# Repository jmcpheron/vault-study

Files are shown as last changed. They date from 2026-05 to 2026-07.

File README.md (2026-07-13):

# Vault Study

We're recreating **Adam Savage's miniature (1/12-scale) bank-vault
door** — the one he machines on his
[Tested YouTube series](https://www.tested.com/) — as a public
**Onshape** model anyone can open and play with. Second act: the
same mechanism converted into a parametric design an FDM printer
can build.

## The model — try it

The faithful variant is a CAD reinterpretation of Adam's machined
design: module-0.5 gears, a 120-tooth ring + 12 × 24-tooth spurs,
12 rack-driven locking pins, a combination lock as gatekeeper.

- **[Open it in Onshape ↗](https://cad.onshape.com/documents/eaf3e87c1faae12ad867b335/w/83a96bb8921d1af3abd7aecd/e/9db299b535aaeded5de5120c)**
  — the live document. Drag the mechanism; with a free Onshape
  account you can copy the workspace and take it apart.
- **[Download the STEP](step-source/)** — the committed export, for
  any other CAD package.
- **[Interactive demo](https://jmcpheron.github.io/vault-study/interactive/)**
  — no CAD required; a slider drives all twelve pins in the browser.

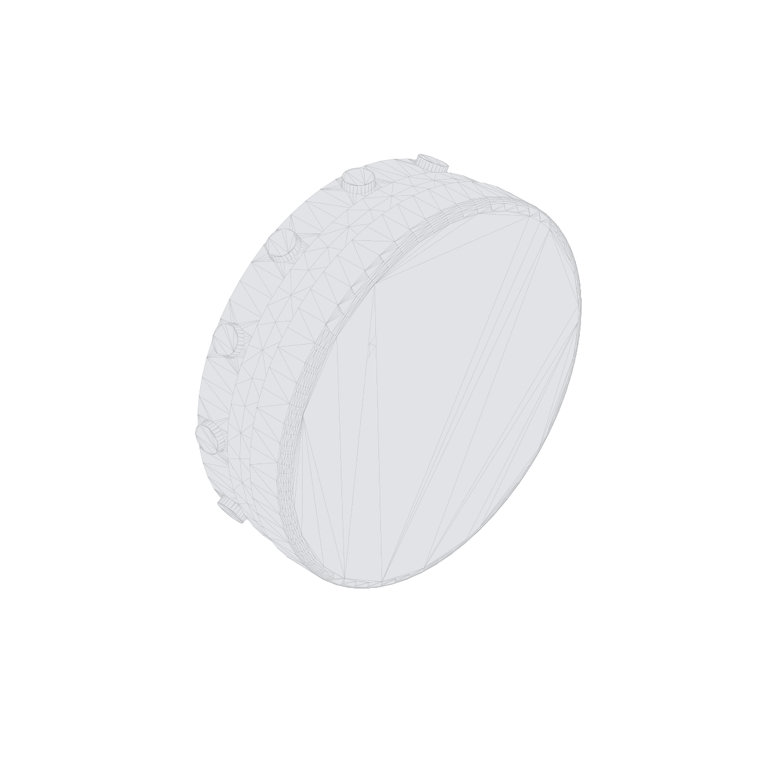
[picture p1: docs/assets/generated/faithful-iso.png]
Faithful variant, isometric render


Both documents are still being built — expect half-finished
geometry, and check the [build blog](https://jmcpheron.github.io/vault-study/)
for where things stand.

## The FDM conversion

The second act redesigns the same mechanism for desktop 3D
printers: cylinders become hex stock (anti-rotation without
keyways), tolerances loosen, parts orient to avoid supports. Aims
to be printable on a stock Bambu A1 / Prusa Mini class machine in
one evening's worth of jobs.

- **[Open the FDM variant in Onshape ↗](https://cad.onshape.com/documents/017898deda56c430272a5497/w/5d7667d0936a708006b152fa/e/8e68069be3521bc23b864206)**
- [`cad/fdm/deviations.md`](cad/fdm/deviations.md) — the home for
  every "why is the FDM one different?" answer.
- End state: a 3MF bundle on **MakerWorld** and **Printables** that
  anyone can print at home without reading any of this. _(Soon.)_

## The blog

**[jmcpheron.github.io/vault-study ↗](https://jmcpheron.github.io/vault-study/)**
— a visual development blog: exploded views, the gear math, pin
tolerance stack-ups, and the design decisions as they happen. The
evergreen reference pages (mechanics, gearing math, faithful-vs-FDM)
live there too.

## What's where

| Path | What it is |
| --- | --- |
| [`specs.md`](specs.md) | Canonical dimensions, source-tagged to the video they came from. The keystone. |
| [`cad/faithful/`](cad/faithful/) | Faithful-variant docs: Onshape doc link, modeling notes, FeatureScript settings. |
| [`cad/fdm/`](cad/fdm/) | FDM-variant docs + [`deviations.md`](cad/fdm/deviations.md). |
| [`step-source/`](step-source/) | Raw STEP exports from Onshape. The inbox; the tooling reads from here. |
| [`docs/`](docs/) | GitHub Pages site: the development blog + reference pages (Jekyll). |
| [`src/vaultkit/`](src/vaultkit/) | Python kernel — gear + tolerance math, and the render pipeline behind the blog's visuals. |
| [`log.md`](log.md) | Terse workshop journal. The blog is its illustrated public face. |

## Status (live links)

| Variant | Onshape | MakerWorld | Printables |
| --- | --- | --- | --- |
| Faithful | [open in Onshape ↗](https://cad.onshape.com/documents/eaf3e87c1faae12ad867b335/w/83a96bb8921d1af3abd7aecd/e/9db299b535aaeded5de5120c) | n/a (CAD study) | n/a (CAD study) |
| FDM | [open in Onshape ↗](https://cad.onshape.com/documents/017898deda56c430272a5497/w/5d7667d0936a708006b152fa/e/8e68069be3521bc23b864206) | _(soon)_ | _(soon)_ |

## How the visuals get made

Every diagram, table, and animation on the blog is *derived* — from
the Onshape STEP exports plus one canonical parameter file — by the
`vaultkit` Python kernel:

```
   Onshape docs ──STEP──▶ step-source/ ──vaultkit──▶ docs/ (blog + SVG/GIF/PNG)
                                             │
                                             └──▶ MakerWorld + Printables (3MF)
```

```bash
# Light install — gear + tolerance math, SVG diagrams, tests
pip install -e ".[dev]"

vaultkit gears info   # the gear-math summary derived from specs.md
vaultkit play         # the pin-play tolerance stack-up, faithful vs FDM

pytest                # includes the specs.md ↔ params.py drift test
ruff check src tests
```

The heavy CAD libraries (cadquery-ocp, trimesh, etc.) power the
STEP inspection and 3D renders and live behind
`pip install -e ".[heavy]"`, so contributors who only want to edit
prose aren't forced into a 180 MB OpenCascade wheel.

The repo follows the **Shareable CAD** pattern (Onshape → GitHub →
MakerWorld/Printables); the pattern doc is
[`SHAREABLE-CAD.md`](SHAREABLE-CAD.md).

## Attribution

Mechanism design, proportions, and gear math are Adam Savage's,
shown on the Tested YouTube series. This repo is an independent
educational CAD reinterpretation. Full attribution and source
links in [`ACKNOWLEDGMENTS.md`](ACKNOWLEDGMENTS.md).

## Licenses

- **Code** (`vaultkit`, tests, configs): MIT — see [`LICENSE`](LICENSE).
- **3D geometry** (STEP files, derived STL/3MF/renders): CC BY-SA 4.0
  — see [`LICENSE-3D-FILES`](LICENSE-3D-FILES).

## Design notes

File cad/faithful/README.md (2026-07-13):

# Faithful variant

A CAD reinterpretation of Adam Savage's machined 1/12-scale vault door
as built on the Tested YouTube series. The geometry follows Adam's
dimensions exactly — same materials called out in [`../../specs.md`](../../specs.md),
same gear math, same combination-lock-as-gatekeeper.

## Onshape document

**Public, view-only:**
[cad.onshape.com/documents/eaf3e87c…](https://cad.onshape.com/documents/eaf3e87c1faae12ad867b335/w/83a96bb8921d1af3abd7aecd/e/9db299b535aaeded5de5120c)

The canonical IDs (document / workspace / element) and the pinned
Onshape **Version** for the current STEP live in
[`../../src/vaultkit/params.py`](../../src/vaultkit/params.py) under
`ONSHAPE["faithful"]` — the one place the tooling reads. Current STEP:
**live workspace export** (no named Version pinned yet).

The Onshape document is the **source of truth** for geometry. The
STEP export sits at [`../../step-source/faithful-vault.step`](../../step-source/faithful-vault.step).
When the Onshape document updates, re-export STEP
and replace that file — see [`../../SHAREABLE-CAD.md`](../../SHAREABLE-CAD.md)
for the cut-a-Version → export → commit loop.

## Modeling conventions

See [`onshape.md`](onshape.md) for FeatureScript settings and the
Assembly-tab mate strategy that turns one modelled spur into the
timed 12-pin mechanism.

## Bill of materials

_(Will be auto-generated by `vaultkit bom` once the heavy pipeline
lands. For now, see [`../../specs.md`](../../specs.md) — every part
and dimension is enumerated there.)_

## Differences from Adam's build (acknowledged, not "fixes")

- We aren't actually building a physical one in cast iron and brass.
  CAD takes the geometry; the materials are FYI.
- The lapping-plate flatness work, the hand-threading concentricity
  fights, the dividing-plate fixturing — all the rich physical-shop
  knowledge from the videos — exists in the docs as commentary
  ([`docs/build-log.md`](../../docs/build-log.md),
  [`docs/sources.md`](../../docs/sources.md)) but doesn't change the
  CAD.

## Related

- [`../fdm/`](../fdm/) — the printable-at-home variant. Same
  mechanism, redesigned for FDM.
- [`../../docs/mechanics.md`](../../docs/mechanics.md) — how the
  whole thing works as a single system.

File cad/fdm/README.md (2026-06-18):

# FDM variant

The same vault mechanism, redesigned for desktop FDM 3D printers.
Aims to print on a stock Bambu A1 / Prusa Mini class machine in one
evening's worth of jobs, no supports required, no post-machining,
no specialty filaments.

Design philosophy: **preserve the mechanism, swap the manufacturing
language.** Cylinders become hex stock so anti-rotation comes from
geometry instead of keyways. Tolerances loosen from "0.020 in
clearance everywhere" to FDM-realistic numbers. Layer orientation
is chosen per-part. See [`deviations.md`](deviations.md) for the
running list of "why is the FDM one different here?" answers.

## Onshape document

**Public, view-only:**
[cad.onshape.com/documents/017898de…](https://cad.onshape.com/documents/017898deda56c430272a5497/w/5d7667d0936a708006b152fa/e/8e68069be3521bc23b864206)

Canonical IDs + the pinned Onshape **Version** for the current STEP
live in [`../../src/vaultkit/params.py`](../../src/vaultkit/params.py)
under `ONSHAPE["fdm"]`. Current STEP: **live workspace export** (no
named Version pinned yet — see
[`../../SHAREABLE-CAD.md`](../../SHAREABLE-CAD.md) for the export loop).

Early STEP export already in
[`../../step-source/fdm-vault.step`](../../step-source/fdm-vault.step).

## Modeling conventions

See [`onshape.md`](onshape.md) for FDM-specific FeatureScript settings
and Assembly notes. Inherits from
[`../faithful/onshape.md`](../faithful/onshape.md); only differences
are recorded.

## Print profile

_(Will live alongside the 3MF bundle once that ships. Aim: 0.2 mm
layer height, 4-wall perimeter on the geared parts, PETG for the
mechanism, PLA for the cosmetic puck.)_

## MakerWorld + Printables

| Site | Status |
| --- | --- |
| MakerWorld | _(not yet listed)_ |
| Printables | _(not yet listed)_ |

When the first listing goes live, paste the URL here, and link back
from the listing description to this repo + the Onshape doc.

## Related

- [`../faithful/`](../faithful/) — the machined-replica variant.
- [`deviations.md`](deviations.md) — the canonical log of FDM
  design choices.
- [`../../docs/fdm-variant.md`](../../docs/fdm-variant.md) — the
  human-facing explainer page about *why* these choices were made.

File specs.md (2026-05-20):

# Vault — specifications

Single source of truth for every dimension, count, and material call-out in
the Adam-Savage-faithful design. Every row is tagged with the source video
it came from (`[part-N]`), so when Adam revises a number in a later video
the trail stays clear.

Numbers here are the **canonical** values for the faithful variant. They
are mirrored into [`src/vaultkit/params.py`](src/vaultkit/params.py) by
hand; the drift test in [`tests/test_no_drift.py`](tests/test_no_drift.py)
fails if the two get out of sync. The FDM variant inherits these defaults
and deviates where noted in [`cad/fdm/deviations.md`](cad/fdm/deviations.md).

When a value is superseded, the old row is kept (struck through, marked
`superseded in [part-N]`) and the new row sits below it (marked `live`).
The history is the lesson — parametric design exists *because* numbers
move. The drift test only checks `live` rows.

Sources legend:

- `[part-1]` — Ring gear machining
  (https://www.youtube.com/watch?v=SiL8IzJSnyU)
- `[part-2]` — Locking pins, racks, main door body
- `[part-3]` — Vault door (heavy puck), frame, hinge
- `[part-4]` — Concentricity, rack refinement, pin-diameter revision
- `[part-5]` — Combination lock

---

## Global gear math

| Parameter | Value | Source |
| --- | --- | --- |
| Gear module | 0.5 mm | [part-1] |
| Scale (relative to a real vault door) | 1/12 | [part-1] |

The module is the parameter that must match across every gear that meshes,
so it is the single most important number in the file. A real vault door
uses 24 spur gears (24 teeth each) around a 288-tooth ring gear; Adam
halves the math for his 1/12-scale build.

## Ring gear

| Parameter | Value | Source |
| --- | --- | --- |
| Teeth | 120 | [part-1] |
| Outer diameter | 2.401 in (≈ 2.4 in) | [part-1] |
| Inner diameter (slip-fit on acrylic boss) | 2.003 in | [part-2] |
| Depth of gear cut (OD to root of tooth) | 0.044 in | [part-1] |
| Material (Adam's build, FYI only) | 416 stainless | [part-1] |

## Spur gears

| Parameter | Value | Source |
| --- | --- | --- |
| Count | 12 | [part-1] |
| Teeth (each) | 24 | [part-1] |
| Bolt-circle diameter (BCD) | 72 mm | [part-2] |
| Bolt-circle hole spacing | 30° (12 holes evenly around) | [part-1] |
| Axle | Shoulder bolt, 0.1 mm smaller than gear bore (slip-fit) | [part-2] |

Adam's mill dividing plate has 24 holes (15° spacing); he fills every
other one for the 12-pin door. In CAD: a 12-point circular pattern on a
72 mm BCD.

## Locking pins

| Parameter | Value | Source | Status |
| --- | --- | --- | --- |
| Count | 12 (one per spur gear) | [part-1] | live |
| Diameter | ~~12 mm~~ | [part-1], [part-2] | superseded in [part-4] |
| Diameter | **10 mm** | [part-4] | live |
| Length | 30 mm | [part-2] | live |
| Base thread | M6 (rack screws into pin base) | [part-2] | live |

The 12 mm → 10 mm revision is the textbook reason this repo is
parametric: change `PIN_DIAMETER_MM` in `params.py` and the radial
bores in the acrylic hub, the cast-iron puck, and the FDM-variant
hex stock all follow.

## Racks (drive the pins)

| Parameter | Value | Source |
| --- | --- | --- |
| Stock | 8 mm × 8 mm square | [part-2] |
| Module (matches ring + spur) | 0.5 mm | [part-2] |
| Threaded end | Turned down to 6 mm shaft, M6 thread | [part-2] |
| Clearance cut | Curved relief on back face (clears ring gear) | [part-2], [part-4] |
| Quantity machined | 14 (need 12; "always make more than you need") | [part-4] |

The threaded stud must be concentric to the 8 × 8 stock to within
~0.0125" or the pins bind on the door bores. Adam fixes this with an
8 mm square 5C collet + spindle lock + tailstock die — see [part-4].

## Main door body (acrylic hub)

The clear-acrylic puck that houses the mechanism and lets the gears
be visible.

| Parameter | Value | Source |
| --- | --- | --- |
| Outer diameter | 6 in | [part-2] |
| Thickness (stock) | 1.25 in | [part-2] |
| Material | Cast acrylic (not extruded — extruded melts on the lathe) | [part-2] |
| Ring-gear slip-fit boss diameter | 2.003 in | [part-2] |
| Radial pin bores | 12 × 12 mm dia | [part-2] |

Note: the radial pin bores were sized to the original 12 mm pins; on
a follow-on revision they need to drop to 10 mm to match the
[locking-pin revision in part-4](#locking-pins). Track that change
here when it lands.

## Heavy door puck (cast iron outer)

| Parameter | Value | Source | Status |
| --- | --- | --- | --- |
| Material | ~~Steel~~ | [part-3] | superseded mid-[part-3] |
| Material | **Cast iron** | [part-3] | live |
| Target weight (real-life) | 15–20 lb | [part-3] | live |
| Outer diameter (fits frame hole) | 6 in | [part-3] | live |
| Front-face thickness (solid) | 0.5 in | [part-3] | live |
| Edge taper (nominal) | ~10° (built as three stepped angles) | [part-3] | live |
| Closure depth into frame | 0.75 in (limited by hinge clearance) | [part-3] | live |

The tapered edge is what makes a vault door "thunk" home into the
frame. Adam estimates ~10° but breaks it into three slightly
different stepped angles — exact values TBD.

## Door frame

| Parameter | Value | Source |
| --- | --- | --- |
| Material | 1/2 in 6061 aluminum plate | [part-3] |
| Overall size | 10–12 in square | [part-3] |
| Door opening (centered) | 6 in dia | [part-3] |
| Door-to-frame clearance | 0.020 in (20 thou) | [part-3] |

## Hinge

| Parameter | Value | Source |
| --- | --- | --- |
| Thrust-bearing OD | 3/8 in | [part-3] |
| Center pin | 1/8 in | [part-3] |
| Fasteners | 28 × M2 screws | [part-3] |
| Hinge-hole inner column (X from door center) | 0.245 in | [part-3] |
| Hinge-hole column spacing | 0.508 in | [part-3] |
| Hinge-hole outer column (X = inner + spacing) | 0.753 in | [part-3] |
| Hinge-hole Y span (± from center) | 0.9125 in | [part-3] |

Adam's Plan B if the M2s fail under load: M6. CAD stays with M2.

## Combination lock

| Parameter | Value | Source |
| --- | --- | --- |
| Cage envelope | 0.75 in × 0.5 in | [part-5] |
| Cage material | 0.025 in (25 thou) brass sheet (~0.5 mm) | [part-5] |
| Combination wheels | 3 | [part-5] |
| Wheel diameter | 0.450 in | [part-5] |
| Wheel features (each) | Spindle hole + drive tab + locking slot | [part-5] |
| Front-dial spindle | 1/8 in brass rod | [part-5] |
| Front-dial divisions | 36 (10° each) | [part-5] |
| Front-dial tick lengths | 3 (short / medium / long, every 1/5/10) | [part-5] |

Bell-crank linkage couples the drop-arm to the ring gear: when the
three wheels' locking slots align, the arm drops, the bell crank
unlocks the ring gear, the user throws the lever, all 12 pins extend.

## Derived values

These fall out of the canonical numbers above. The kernel computes
them in [`gears.py`](src/vaultkit/gears.py) so prose can read them
without hard-coding.

| Parameter | Value | Derivation |
| --- | --- | --- |
| Drive ratio (ring : spur) | 5 : 1 | 120 / 24 |
| Teeth between adjacent spur-gear axes | 10 | 120 / 12 (timing math, [part-2]) |
| Ring-gear pitch diameter | 60 mm | module × teeth = 0.5 × 120 |
| Spur-gear pitch diameter | 12 mm | module × teeth = 0.5 × 24 |
| Spur-gear axis radius (from door center) | 36 mm | (ring PD + spur PD) / 2 |

The 36 mm spur-axis radius derived from gear math should match the
72 mm BCD measured by Adam (= 2 × 36). It does — and that
agreement is one of the things the [drift test](tests/test_no_drift.py)
silently confirms.

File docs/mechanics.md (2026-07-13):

---
title: Mechanics overview
---

# Mechanics overview

<p style="text-align:center; margin: 1em 0;">
  <picture>
    <source srcset="{{ '/assets/generated/mechanism-exploded-fdm.webp' | relative_url }}" type="image/webp">
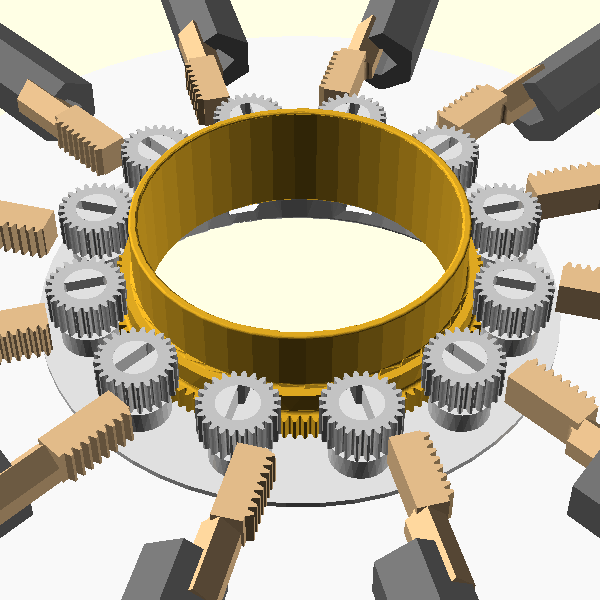
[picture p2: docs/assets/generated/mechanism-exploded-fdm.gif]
The vault mechanism in an exploded view: ring gear, twelve spur gears, twelve racks, twelve locking pins, hub plate, and base, fanning out radially from their assembled positions and returning.
    
  </picture>
</p>

The vault is a **one-knob lock**. We turn the dial, twelve pins shoot
outward into the frame in unison, and that's the whole thing. Under
the hood it's a chain of three motions, each multiplying the last:

1. **Combination lock → bell crank → ring gear.** Three watchmaker-scale
   wheels in a brass cage form the lock. Dial the right combination,
   a drop arm falls through three aligned slots, a bell crank pivots,
   and the giant **120-tooth ring gear** at the centre of the door is
   released. See [the combination lock]({{ '/combination-lock/' | relative_url }}).
2. **Ring gear → twelve spur gears.** The ring's 120 internal teeth
   mesh with twelve identical **24-tooth spur gears** spaced 30°
   apart. One turn of the ring spins every spur five times. The
   tooth-count ratio is 120 : 24 = 5 : 1; the
   [gearing-math page]({{ '/gearing-math/' | relative_url }}) walks through where the 5
   comes from.
3. **Spur gears → racks → pins.** Each spur drives a square **8 mm × 8 mm
   rack** with module-0.5 teeth on one face. The rack carries a
   **10 mm locking pin** threaded onto its end. As the spur rotates,
   the rack — and the pin attached to it — translates radially
   outward, through a bore in the door body, and into a matching bore
   in the frame.

With all twelve pins extended, the door is locked: each pin couples
it to the surrounding frame. Unlock the bell crank, throw the lever
in reverse, every pin retracts at once, and the door swings open. One
input, twelve coordinated motions — the whole point of the gear
chain.

The chain is **timed**: ring teeth (120) divided by pin count (12)
is 10. There are exactly ten ring teeth between adjacent spur axes.
The arithmetic isn't optional. If 120 ÷ 12 weren't a whole number,
the spurs couldn't all sit in matching phase relative to the ring's
tooth pattern, and the racks would push their pins to subtly
different depths. Adam emphasises this in
[part-2 of the build series]({{ '/sources/' | relative_url }}); the kernel enforces it in
[`vaultkit.gears.teeth_between_satellites`](https://github.com/jmcpheron/vault-study/blob/main/src/vaultkit/gears.py).

## The 12-spur crowding question

The animated diagram above places the twelve spur centres at the
**gear-math-derived radius** of 24 mm from the door centre — the
distance at which the spurs' teeth actually mesh with the ring's. At
that radius, twelve spurs of 12 mm diameter each are nearly
touching (their centres are 12.57 mm apart on the bolt circle, against
spur diameters of 12 mm — 0.57 mm of physical clearance). Adam's
build-video measurements report a 72 mm bolt-circle (36 mm radius),
where the spurs are much further apart — but at 36 mm, the spur teeth
would never reach the ring at all.

There's a real CAD discrepancy here, called out in
[`specs.md`](https://github.com/jmcpheron/vault-study/blob/main/specs.md#derived-values).
The [interactive page]({{ '/interactive/' | relative_url }}) lets you flip between the
two layouts and see the difference.

## See also

- [Gearing math]({{ '/gearing-math/' | relative_url }}) — module, tooth counts, where 5 : 1 comes from.
- [Interactive builder]({{ '/interactive/' | relative_url }}) — drag the slider, watch the pins extend.
- [Why twelve pins?]({{ '/why-twelve-pins/' | relative_url }}) — the divisor argument and base-12 elegance.
- [The combination lock]({{ '/combination-lock/' | relative_url }}) — the gatekeeper at the start of the chain.
- [Faithful vs FDM]({{ '/faithful-vs-fdm/' | relative_url }}) — what changes when you redesign for 3D printers.

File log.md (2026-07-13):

# Build log

Reverse-chronological session notes. Newest entries on top. Format
suggestion (not enforced): a date heading, then any mix of what you
modeled, what you learned, what you had to revise, what you got stuck
on. Keep it short — this is for future-you, not for an audience. The
public, illustrated version of this journal is the
[build blog](https://jmcpheron.github.io/vault-study/); this file
stays the terse workshop record.

---

## 2026-07-13 — Refocus: the site is now a build blog

Re-weighted the repo around what it was always about: the Onshape
model first (open it, drag it), the FDM conversion second, the
tooling demoted to a supporting role. The Pages front page is now a
chronological build blog seeded with five posts — kickoff, the
pin-travel math, the 12 mm → 10 mm pin story, the exploded views,
and a new pin-play tolerance stack-up backed by `vaultkit play` and
a generated diagram. Removed the `vault-notes-from-youtube/` scratch
as promised, and fixed every inter-page link the pretty-permalink
setup had silently broken.

## 2026-05-19 — Repo bootstrap

Scaffolded the repo following the Shareable CAD pattern, flattened
for a single project. Two parallel variants (faithful + FDM), both
already seeded as STEP exports in [`step-source/`](step-source/).
Absorbed the `vault-notes-from-youtube/` scratch (since removed)
into the canonical [`specs.md`](specs.md), including the
12 mm → 10 mm pin-diameter revision from part-4 (kept both rows
visible — the lesson is *why* the design is parametric, not just
the latest number). The `vaultkit` Python kernel ships with real
gear math, a `params.py` mirror, and stubs for the heavier
STEP/render pipeline. CI runs lint + tests; Pages deploys from
`/docs`; the auto-commit STEP-artifact workflow is wired up but
`workflow_dispatch`-only until the stubs are real.

What's next: open the two Onshape documents, paste the URLs into
[`cad/faithful/README.md`](cad/faithful/README.md) and
[`cad/fdm/README.md`](cad/fdm/README.md), then start filling in
the explainer pages.

## 2026-05-06 — Kickoff

We watched Adam Savage machine a 1/12-scale bank-vault door on
Tested and couldn't stop thinking about the mechanism: one ring
gear, twelve spur gears, twelve pins, all timed off tooth counts
you can verify by eye. We're rebuilding it in Onshape to learn
assemblies end-to-end — gear relations, rack-and-pinion mates,
sub-assembly patterns — with the gear math checked in code along
the way. Done looks like two things: a public Onshape document
anyone can open and drag, and an FDM-printable conversion anyone
can print. We are intentionally not machining one.

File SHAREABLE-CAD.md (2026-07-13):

# Shareable CAD — pattern reference

This is the supporting pattern doc for the tooling. The project's
front door is the Onshape model and the
[build blog](https://jmcpheron.github.io/vault-study/); this file
explains the pipeline that keeps them honest.

This repository follows the **Shareable CAD** pipeline pattern:

```
   Onshape doc          ← source of truth (parametric CAD in the cloud)
       │ STEP export, committed to the repo
       ▼
   GitHub repo          ← Python tooling, parameters, history, issues
       │ auto-built artifacts (STL / GLB / GIF / SVG / explainer pages)
       ▼
   MakerWorld + Printables   ← consumer-facing sharing endpoints
                              (3MF bundle + slicer profile + photos)
```

The pattern was first developed in the sibling `pycon2026` repo
across three projects (a PyCon gear card, a spiral-spring cat toy,
and the early stages of this vault study). It's flattened here for a
single-project repo.

The core ideas, applied here:

1. **Parametric.** Every dimension lives in
   [`src/vaultkit/params.py`](src/vaultkit/params.py) — one Python
   module, mirrored into the Onshape variable sheet by hand.
2. **Code-trackable.** A parameter change is a one-line git diff
   with a date and a commit message. Not a screenshot of an Onshape
   revision label.
3. **Derivable.** Every artifact a reader might want — explainer
   page, hero render, exploded GIF, BOM — is *built* by
   [`vaultkit`](src/vaultkit/) from `params.py` plus the STEP file.
4. **Printable.** The end state is a 3MF bundle on MakerWorld and
   Printables that anyone can print at home without reading any of
   this.

## Re-exporting from Onshape (the version loop)

The git ↔ Onshape link is deliberate. When the model reaches a
milestone worth freezing:

1. **Cut a named Version in Onshape** (the version graph → *Create
   version*, e.g. `v0.1 — first public export`). A Version is
   immutable; a workspace keeps moving.
2. **Export STEP from that Version** and drop it in
   [`step-source/`](step-source/), replacing the existing file.
3. **Bump the provenance** in
   [`src/vaultkit/params.py`](src/vaultkit/params.py) →
   `ONSHAPE[variant]`: set `version_id`, `version_name`, and
   `exported_utc`. `OnshapeSource.permalink` then resolves to the
   immutable `/v/<versionId>` URL the release descriptions link to.
4. **Commit the STEP and the params bump together.** Now `git log` of
   `params.py` and the Onshape version graph tell the same story:
   which commit's files came from which Onshape Version.

Until a Version is cut, `version_id` stays `None` and everything
points at the live `/w/` workspace URL — fine for an early public
doc, just not a frozen snapshot.

The full pattern doc lives in the `pycon2026` repo. This file is a
pointer; if `pycon2026/SHAREABLE-CAD.md` updates with new
conventions, port them back here.

Companion files in *this* repo:

- [`README.md`](README.md) — front-door story.
- [`specs.md`](specs.md) — canonical dimensions; source of truth for
  numbers that appear in prose and code alike.
- [`cad/faithful/`](cad/faithful/) and [`cad/fdm/`](cad/fdm/) — the
  two parallel CAD variants.
- [`src/vaultkit/`](src/vaultkit/) — the Python kernel.
- [`docs/`](docs/) — GitHub Pages explainer site.

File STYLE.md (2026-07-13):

# Style guide

A short editorial guide for the prose in this repo and on its Pages
site. The voice is **casual but the engineering is respected** — we
let ourselves be informal, but the numbers, the citations, and the
mechanism stay sober.

These are the rules. Each one is here because we've watched it
matter. Skipping them is fine if you have a reason; ignoring them
because the prose felt nicer that way is not.

## The seven rules

1. **Active voice, first-person plural.** "We measured the bore at
   18 mm." Not "the bore was measured" and not "Adam measured the
   bore" — the implicit narrator is the project, not a person.

2. **Jokes live in prose, never in code.** Headings, intros, asides
   can be funny. Identifiers, comments, docstrings, dimension tables,
   commit messages, and `params.py` constants stay deadpan. A pun in
   a variable name is a debt that compounds.

3. **No emoji in prose.** One exception: a single load-bearing glyph
   as a section-header marker (a warning ⚠, a link-out ↗). Never
   decorative. Never in body text.

4. **Numbers are sacred.** Any dimension, ratio, or tolerance is
   stated precisely with units. "About / roughly" only appears next
   to an exact figure ("the bore is 17.95 mm — call it 18"). Never
   on its own ("the bore is roughly 18-ish mm" is banned).

5. **Puns must be shorter than the sentence containing them.** If
   the joke takes more words than the point it lands on, cut the
   joke.

6. **Hedge claims, not measurements.** "We *think* the original used
   a 12-tooth pinion" is fine. "The bore is *roughly 18-ish* mm" is
   not. If we don't know the number, we say so and link to where
   the question lives.

7. **Link out, don't paraphrase.** Adam's videos, math identities,
   library docs — when we're citing them, we link. Re-stating
   someone's explanation is how factual drift starts.

## Hero-collision policy

One animated element per viewport on a Pages page. The split:

- **Animated SVG hero** on text/explainer pages — the gear-mesh on
  `gearing-math.md`, the full mechanism on `interactive.md`.
- **GIF hero** on visual/showcase pages — `mechanism-cam-sweep-fdm.gif`
  on `index.md`, `mechanism-exploded-fdm.gif` on `mechanics.md`,
  iso PNGs on `faithful-vs-fdm.md`.

If a page wants both, pick one for above-the-fold and put the other
below an `## H2`.

Blog posts follow the same rule — one animated element per
viewport. Two more post conventions: excerpts on the front-page
stream are text-only (declare `excerpt:` in the front matter; the
default excerpt grabs the post's H1), and every asset or page link
inside a post goes through `relative_url` — posts nest four levels
deep under pretty permalinks, so bare `assets/…` links are bugs.

## Variant-name conventions

- **Faithful** — the CAD reinterpretation of Adam's machined design.
  Lowercase in prose, no scare quotes.
- **FDM** — the 3D-printer-friendly variant. Uppercase, no hyphen.
- The faithful STEP export was originally committed as
  `unauthorized-vault-clone.step` — a wink. Renamed to
  `step-source/faithful-vault.step` when the repo refocused on
  "open it and try it": the symmetric `faithful-vault.step` /
  `fdm-vault.step` pair is clearer for a newcomer downloading files.

## What not to commit

- The `.venv/`, `.pytest_cache/`, `.ruff_cache/`, `__pycache__/`
  noise (`.gitignore` handles them).
- `/tmp/vaultkit-cache/` — STL cache, regenerated on demand.
- `.DS_Store` files (already in `.gitignore`).
- Frames from intermediate OpenSCAD runs — only commit the final
  GIF + WebP.

## Generated artifacts

`docs/assets/generated/` and `docs/_includes/mechanism-interactive.svg`
are **derived** from the kernel + `params.py`. To regenerate after a
parameter change:

```bash
vaultkit explain render
```

Then commit the regenerated artifacts. (CI auto-commit is wired up
but `workflow_dispatch`-only until the OpenSCAD package on Ubuntu
catches up.)

## Where the principles live

This file is the **contributor** style guide — editorial
conventions, naming, what to commit. The **public-facing** statement
of what the project believes is `docs/principles.md`. They share
spirit but serve different audiences.

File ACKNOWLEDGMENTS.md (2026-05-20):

# Acknowledgments

## Adam Savage's vault-door build series

This repository exists because **Adam Savage** built a 1/12-scale
mechanical bank-vault door on camera, on the
[Tested YouTube channel](https://www.tested.com/), and showed every
gear ratio, every dimension, every machining decision. The mechanism
design, the proportions, the 12-pin layout, the 120 / 24 gear math
— that's all Adam's work. This repo is an independent CAD
reinterpretation and FDM-friendly redesign for educational and hobby
purposes, with sources tracked back to the original videos in
[`specs.md`](specs.md) and [`docs/sources.md`](docs/sources.md).

If you found this repo and you haven't watched Adam's series, go do
that first. The videos are the original work; everything here is
commentary.

## Third-party tools

- **[Onshape](https://www.onshape.com/)** — cloud parametric CAD;
  source of truth for the geometry. Free hobbyist tier with public
  documents.
- **[OpenSCAD](https://openscad.org/)** — used by `vaultkit` for
  orthographic renders and the FDM-variant sandbox.
- **[build123d](https://github.com/gumyr/build123d)** /
  **[CadQuery](https://github.com/CadQuery/cadquery)** — Python CAD
  libraries used by the `vaultkit[heavy]` extras for mesh
  operations and render generation.
- **[trimesh](https://github.com/mikedh/trimesh)** — STL/3MF reading
  and mesh manipulation.
- **[drawsvg](https://github.com/cduck/drawsvg)** — SVG diagrams in
  the explainer pages.

## Pattern reference

The repo layout follows the "Shareable CAD" pattern developed in
the sibling `pycon2026` repo — see [`SHAREABLE-CAD.md`](SHAREABLE-CAD.md).

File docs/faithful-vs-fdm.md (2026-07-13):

---
title: Faithful vs FDM
---

# Faithful vs FDM, side by side

Two variants in parallel: a CAD reinterpretation of Adam Savage's
machined design and a redesign for desktop 3D printers. They share
the mechanism — module 0.5 gears, 12 pins, 120/24 tooth counts — and
diverge on everything to do with manufacturing.

This page is the diff. We show what's currently in each STEP file,
what the geometry choices reveal about the two design philosophies,
and what each variant is still missing relative to
[`specs.md`](https://github.com/jmcpheron/vault-study/blob/main/specs.md).

All numbers below come from `vaultkit step inspect`, run against
the two STEP files in
[`step-source/`](https://github.com/jmcpheron/vault-study/tree/main/step-source).

## At a glance

| | Faithful (Adam-replica) | FDM (printable) |
|---|---|---|
| STEP file | [`faithful-vault.step`](https://github.com/jmcpheron/vault-study/blob/main/step-source/faithful-vault.step) | [`fdm-vault.step`](https://github.com/jmcpheron/vault-study/blob/main/step-source/fdm-vault.step) |
| Onshape doc | [open in Onshape ↗](https://cad.onshape.com/documents/eaf3e87c1faae12ad867b335/w/83a96bb8921d1af3abd7aecd/e/9db299b535aaeded5de5120c) | [open in Onshape ↗](https://cad.onshape.com/documents/017898deda56c430272a5497/w/5d7667d0936a708006b152fa/e/8e68069be3521bc23b864206) |
| Bounding box (mm) | 171 × **50** × 171 | 171 × **31** × 171 |
| Body shape | Chunky puck (mimics Adam's cast-iron cylinder) | Thin washer with radial cutouts |
| Triangle count @ 0.5 mm | 50,896 | 60,428 |
| Total STEP entities | 37,633 | 48,924 |
| Tapers / fillets / ellipses | ❌ none | ✅ present |
| Assembly instances | 26 | 39 |

The X/Z dimensions are nearly identical (within 0.2 mm) — both
target a 6-inch / ~152 mm outer-diameter envelope. The Y dimension
is what tells us the story:

- **Faithful: 50 mm (~1.97")** — closer to the combined acrylic-hub
  (1.25") + cast-iron-puck face thickness. The geometry mimics the
  deep, machined cylinder Adam works from.
- **FDM: 31 mm (~1.22")** — matches the 1.25-inch acrylic-hub
  thickness from [`specs.md`](https://github.com/jmcpheron/vault-study/blob/main/specs.md#main-door-body-acrylic-hub).
  The FDM redesign flattens everything to fit on a 3D-printer build
  plate.

## The two designs

### Faithful

Faithful variant, isometric render

The faithful (in-progress) Onshape redesign of Adam's lathe-made
vault. Notable features visible from the iso view:

- **Pin bores on the side rim** — the 12 radial holes for the
  locking pins open through the cylindrical side of the puck, as
  they would on the real vault.
- **Solid puck profile** — the body is one chunky cylinder, not
  yet hollowed out for the gear mechanism. The internal cavity
  Adam mentions in part-3 (see [`specs.md`](https://github.com/jmcpheron/vault-study/blob/main/specs.md#heavy-door-puck-cast-iron-outer))
  (0.5" solid front face, hollow middle, 0.75" closure depth)
  isn't modeled yet.
- **No tapers, fillets, or ellipses** in the STEP entity histogram —
  the 10° edge taper from [`specs.md`](https://github.com/jmcpheron/vault-study/blob/main/specs.md#heavy-door-puck-cast-iron-outer)
  hasn't been added.

What it has so far: the basic puck volume, the side-bored pin
holes, and the two gear products in the assembly.

### FDM

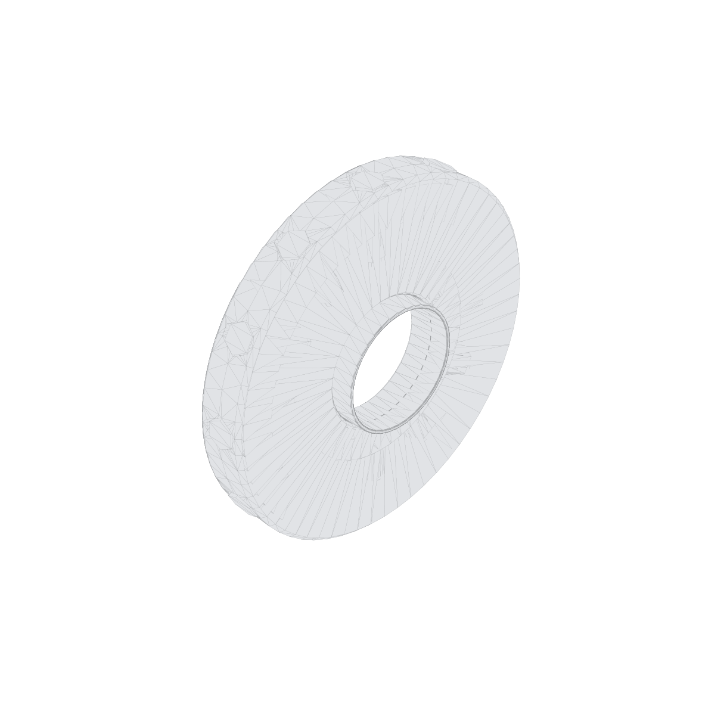
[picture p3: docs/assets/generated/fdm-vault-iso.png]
FDM variant, isometric render


The FDM-printer-friendly variant. The geometry decisions read
loudly:

- **Donut/washer profile** — the body is a thin flat plate with a
  big central hole. The ring gear sits in the central cavity; the
  spur gears mount in the radial bays around it.
- **12 radial slots** visible in the disc — the cutouts that
  accommodate the spur-and-pin sub-assemblies, replacing the
  side-drilled pin bores of the faithful version. Each part lays
  flat on the build plate.
- **Conical, toroidal, and elliptical surfaces present** in the
  STEP entity histogram — those are the FDM-specific fillets,
  chamfers, and rounded edges that make a part 3D-printable without
  fragile sharp corners.
- **More assembly instances** (39 vs 26) and **more total
  geometry** (49K entities vs 38K) — the FDM design is further
  along in detail, not behind.

The FDM design philosophy in one line: **preserve the mechanism,
swap the manufacturing language.** Same 12 pins, same 120/24 gear
math, same combination-lock-as-gatekeeper — but the body becomes a
stack of flat printable plates instead of a chunky machined puck.

## What both files share

- Both export from Onshape via the ST-Developer / STEP Tools
  toolchain (AP242 Edition 2).
- Both contain exactly four named products: `Assembly N`, `Part 1`
  (the body), `Spur gear (120 teeth)` (the ring — Onshape's Spur
  Gear FeatureScript labels internal gears the same way), and
  `Spur gear (24 teeth)` (the satellites).
- Both reach a ~152 mm outer diameter (the 6-inch door target).
- Both currently model only the **central mechanism**: hub + ring +
  spurs. Nothing else from [`specs.md`](https://github.com/jmcpheron/vault-study/blob/main/specs.md)
  is in either STEP yet.

## What's missing from both (still in spec, not in CAD)

The gap between [`specs.md`](https://github.com/jmcpheron/vault-study/blob/main/specs.md)
and either STEP file:

| Subsystem | In faithful STEP? | In FDM STEP? | Spec section |
|---|---|---|---|
| Ring gear + 12 spur gears | ✅ | ✅ | [Ring/Spur](https://github.com/jmcpheron/vault-study/blob/main/specs.md#ring-gear) |
| Locking pins (12 × 10 mm dia × 30 mm) | ❌ | ❌ | [Locking pins](https://github.com/jmcpheron/vault-study/blob/main/specs.md#locking-pins) |
| Racks (8×8 mm, M6 stud, ball-mill relief) | ❌ | ❌ | [Racks](https://github.com/jmcpheron/vault-study/blob/main/specs.md#racks-drive-the-pins) |
| Heavy cast-iron puck (10° taper, 0.75" depth) | ❌ | n/a (intentional) | [Heavy door puck](https://github.com/jmcpheron/vault-study/blob/main/specs.md#heavy-door-puck-cast-iron-outer) |
| Frame (½" 6061, 6" opening) | ❌ | n/a (deferred) | [Door frame](https://github.com/jmcpheron/vault-study/blob/main/specs.md#door-frame) |
| Hinge (3/8" bearings, 28 × M2) | ❌ | n/a (deferred) | [Hinge](https://github.com/jmcpheron/vault-study/blob/main/specs.md#hinge) |
| Combination lock (3 wheels in 0.75"×0.5" cage) | ❌ | ❌ | [Combo lock](https://github.com/jmcpheron/vault-study/blob/main/specs.md#combination-lock) |

`n/a (intentional)` means the FDM variant chose to skip that
subsystem on purpose — see
[`cad/fdm/deviations.md`](https://github.com/jmcpheron/vault-study/blob/main/cad/fdm/deviations.md).
`❌` means it's still on the to-do list.

## Why the FDM file is more developed

A surprise we hit while writing this page: the FDM STEP has **28
conical surfaces, 8 toroidal surfaces, 193 ellipses**. The faithful
STEP has **zero of each**.

That's not a mistake — it's two different states of progress:

- The **FDM variant** has gotten farther in the redesign, including
  the fillets, chamfers, and rounded transitions that make
  individual parts printable. Sharp corners snap on FDM prints; we
  rounded them off, which means lots of curved surfaces in the
  geometry.
- The **faithful variant** is still at the "block out the basic
  shapes" stage. The 10° tapered edge from part-3 — which would
  produce conical surfaces in the STEP — hasn't landed yet.

So the FDM variant isn't simpler. It's *more refined, in a different
direction*.

## Reproducing this page

Every number and image above came from these commands. Re-run them
after re-exporting either STEP from Onshape and the page updates:

```bash
# Inspect (prints the same data the table rows are pulled from)
vaultkit step inspect step-source/fdm-vault.step
vaultkit step inspect step-source/faithful-vault.step

# Hero PNGs (writes to docs/assets/generated/)
vaultkit step render step-source/fdm-vault.step \
    --out docs/assets/generated/fdm-vault-iso.png
vaultkit step render step-source/faithful-vault.step \
    --out docs/assets/generated/faithful-iso.png
```

## See also

- [`cad/faithful/`](https://github.com/jmcpheron/vault-study/tree/main/cad/faithful) — faithful-variant docs, Onshape conventions.
- [`cad/fdm/deviations.md`](https://github.com/jmcpheron/vault-study/blob/main/cad/fdm/deviations.md) — the canonical FDM-deviation log.
- [Gearing math]({{ '/gearing-math/' | relative_url }}) — what the shared mechanism actually computes to.

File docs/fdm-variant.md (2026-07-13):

---
title: FDM design considerations
---

# FDM design considerations

_(Stub — to be written. Goal: explain the design choices that make
the FDM variant printable at home: cylinders → hex stock for
anti-rotation, tolerance loosening for FDM hole stack-up, layer
orientation per part, support-free part design. Each choice cites
back to a specific entry in the
[deviations log](https://github.com/jmcpheron/vault-study/blob/main/cad/fdm/deviations.md).)_

The canonical record of every FDM-specific decision lives in
[`cad/fdm/deviations.md`](https://github.com/jmcpheron/vault-study/blob/main/cad/fdm/deviations.md).
This page is the human-facing explanation of *why*.

## See also

- [Pin travel]({{ '/pin-travel/' | relative_url }}) — the kinematic math, identical for
  both variants (module, tooth counts, and ratio are preserved).
- [Faithful vs FDM]({{ '/faithful-vs-fdm/' | relative_url }}) — STEP-level differences.

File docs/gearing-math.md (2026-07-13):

---
title: The gearing math
---

# The gearing math

<p style="text-align:center; margin: 1em 0;">
  A 120-tooth internal ring gear meshes with a 24-tooth spur gear. The spur counter-rotates at five times the ring's angular speed.
</p>

The vault has just one number that matters more than any other: the
**gear module**.

## Module: the meshing constant

Module is a metric gear-design parameter. For two gears to mesh, they
must share the same module. The vault uses **module 0.5 mm** for
every gear — the 120-tooth ring, all twelve 24-tooth spurs, and the
toothed face of each rack.

> If you change `MODULE_MM` in
> [`src/vaultkit/params.py`](https://github.com/jmcpheron/vault-study/blob/main/src/vaultkit/params.py),
> you change every gear in the assembly. That's what "parametric"
> means in practice.

## Pitch diameters fall out for free

Given module and tooth count, the pitch diameter (the imaginary circle
where the gears effectively touch) is just:

```
pitch_diameter = module × tooth_count
```

For the vault:

| Gear | Teeth | Pitch diameter |
| --- | --- | --- |
| Ring | 120 | 60 mm |
| Spur (×12) | 24 | 12 mm |

The ring is an **internal** gear (teeth point inward), so meshing
spurs sit *inside* its pitch circle. The center-to-center distance
between the ring's axis and any spur's axis is the **difference** of
the pitch radii:

```
center_distance = ring.pitch_radius - spur.pitch_radius
                = 30 mm - 6 mm
                = 24 mm
```

Two times that distance (the spurs sit on a circle around the ring)
is **48 mm — wait, no.** The bolt-circle diameter Adam measured in
part-2 is **72 mm**. That means the spurs sit on a 36 mm radius
from the door center, not a 24 mm radius. The two numbers don't
agree — and the disagreement is informative.

Resolving: the 72 mm BCD measures the *bolt-circle*, i.e. where the
shoulder bolts go through the acrylic puck. That circle is sized for
the spur gear's *axis position*, which lives at `ring_pitch_radius -
spur_pitch_radius` = **24 mm from center, i.e. 48 mm BCD on the gear
math alone.** The 72 mm BCD must therefore include geometry the gear
math doesn't see — likely an offset Adam added between the ring's
pitch circle and the acrylic's gear-mount face, or a different
interpretation of "where the spurs sit." This is exactly the kind of
discrepancy a future drift test should flag.

For now, [`gears.py`](https://github.com/jmcpheron/vault-study/blob/main/src/vaultkit/gears.py)
reports the derived center distance and prints both numbers side by
side in `vaultkit gears info` so the inconsistency is visible, not
hidden.

## The 5:1 ratio

The drive ratio of two meshing gears is `driven_teeth / driver_teeth`.
Drive the ring (120 teeth) → the spur (24 teeth) turns at **5×** the
ring's angular velocity. That's the only ratio in the system: one
rotation of the main lever → 5 rotations of each of the twelve
spurs → about 6 mm of pin travel (depending on rack length).

## Timing: 120 / 12 = 10

This is the wisdom Adam emphasises in part-2. The ring's tooth
count (120) must be **divisible by the number of pins** (12). If
it weren't, the spurs couldn't all sit at the same orientation
relative to the ring's teeth — they'd be slightly out of phase, and
the racks would push the pins to subtly different depths.

120 ÷ 12 = 10 means there are exactly 10 ring-teeth between the
center of any adjacent pair of spur-gear axes. The geometry doesn't
care which 10 — but the count must be a whole number. Real vaults
use 24 spurs around a 288-tooth ring: 288 ÷ 24 = 12. Same trick.

The kernel encodes this rule explicitly:
[`gears.teeth_between_satellites`](https://github.com/jmcpheron/vault-study/blob/main/src/vaultkit/gears.py)
raises `ValueError` if you try a non-divisible combination.

## The Spur Gear FeatureScript

Onshape's standard custom-feature library has a "Spur Gear"
generator. The settings the vault needs:

| Gear | Module | Teeth | Mode |
| --- | --- | --- | --- |
| Ring | 0.5 | 120 | Internal Gear |
| Spur (×12) | 0.5 | 24 | External (default) |

That's the whole input list. Onshape handles the involute profile,
the addendum, the root fillet, the everything-else of gear-tooth
geometry. **Don't try to sketch the teeth by hand.** The Spur Gear
FeatureScript is the single biggest reason this project is feasible
without a degree in mechanical engineering.

## See also

- [`specs.md`](https://github.com/jmcpheron/vault-study/blob/main/specs.md)
  — the canonical numbers, source-tagged to the videos they came from.
- [`src/vaultkit/gears.py`](https://github.com/jmcpheron/vault-study/blob/main/src/vaultkit/gears.py)
  — the math, in 60 lines of pure Python.
- [Why twelve pins?]({{ '/why-twelve-pins/' | relative_url }}) — the divisor argument
  pushed further.

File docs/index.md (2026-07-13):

---
title: Vault Study
---

<style>
.hero {
  margin: 1.5em auto 0.5em;
  text-align: center;
}
.hero picture, .hero img {
  display: inline-block;
  max-width: min(100%, 560px);
  height: auto;
  border-radius: 10px;
  box-shadow: 0 6px 20px rgba(0,0,0,0.08);
}
.elevator {
  text-align: center;
  font-size: 1.15rem;
  color: #444;
  max-width: 580px;
  margin: 0.5em auto 1em;
}
.try-model {
  text-align: center;
  color: #586069;
  max-width: 580px;
  margin: 0 auto 2em;
  font-size: .95rem;
}
.nav-cards {
  display: grid;
  grid-template-columns: repeat(auto-fit, minmax(220px, 1fr));
  gap: 1rem;
  margin: 2rem 0;
}
.nav-cards a {
  display: block;
  padding: 1.1rem 1.2rem;
  border: 1px solid #e1e4e8;
  border-radius: 8px;
  text-decoration: none;
  color: inherit;
  transition: transform .15s, border-color .15s, box-shadow .15s;
}
.nav-cards a:hover {
  transform: translateY(-2px);
  border-color: #159957;
  box-shadow: 0 4px 12px rgba(21,153,87,0.10);
}
.nav-cards h3 { margin: 0 0 .35rem; color: #159957; font-size: 1.05rem; }
.nav-cards p  { margin: 0; color: #586069; font-size: .92rem; }
.post-list h3 { margin-bottom: .1rem; }
.post-list .post-date { color: #586069; font-size: .88rem; }
</style>

<p class="hero">
  <picture>
    <source srcset="{{ 'assets/generated/mechanism-cam-sweep-fdm.webp' | relative_url }}" type="image/webp">
    A 1/12-scale vault mechanism: a 120-tooth ring gear oscillates, driving twelve 24-tooth spur gears, which drive twelve racks and pins radially outward and back.
  </picture>
</p>

<p class="elevator">
We're modeling Adam Savage's miniature bank-vault door in Onshape —
open the document and play with it — and converting it into a
parametric design an FDM printer can build.
</p>

<p class="try-model">
<strong>Try the model:</strong>
<a href="https://cad.onshape.com/documents/eaf3e87c1faae12ad867b335/w/83a96bb8921d1af3abd7aecd/e/9db299b535aaeded5de5120c">faithful in Onshape ↗</a> ·
<a href="https://cad.onshape.com/documents/017898deda56c430272a5497/w/5d7667d0936a708006b152fa/e/8e68069be3521bc23b864206">FDM in Onshape ↗</a> ·
STEP downloads: <a href="https://github.com/jmcpheron/vault-study/tree/main/step-source">step-source/ on GitHub</a>
</p>

## Build blog

The development log, illustrated — exploded views, gear math,
tolerance stack-ups, and the occasional revision Adam makes for us
mid-series.

<div class="post-list" markdown="1">
{% for post in site.posts %}
### [{{ post.title }}]({{ post.url | relative_url }})

<span class="post-date">{{ post.date | date: "%Y-%m-%d" }}</span>

{{ post.excerpt }}
{% endfor %}
</div>

[All posts]({{ 'build-log/' | relative_url }}) ·
[RSS feed]({{ 'feed.xml' | relative_url }})

## Reference pages

<div class="nav-cards">
  <a href="{{ 'interactive/' | relative_url }}">
    <h3>Interactive demo</h3>
    <p>Drag a slider, watch twelve pins extend in unison.</p>
  </a>
  <a href="{{ 'mechanics/' | relative_url }}">
    <h3>How it works</h3>
    <p>Ring → spurs → racks → pins, in 200 words.</p>
  </a>
  <a href="{{ 'faithful-vs-fdm/' | relative_url }}">
    <h3>Faithful vs FDM</h3>
    <p>What we kept, what we changed, why.</p>
  </a>
  <a href="{{ 'principles/' | relative_url }}">
    <h3>Principles</h3>
    <p>Five things this project believes.</p>
  </a>
</div>

## The whole machine in one paragraph

A 120-tooth ring gear sits in the centre of an acrylic puck. Twelve
24-tooth spur gears surround it; each drives a rack-and-pinion that
pushes a locking pin radially outward into the vault frame. A
miniature 3-wheel combination lock is the gatekeeper — dial the
right combination, a bell crank releases the ring gear, and a single
throw of the lever shoots all twelve pins at once. The rest of the
project is dimensions.

## More to dig into

- [Pin travel]({{ 'pin-travel/' | relative_url }}) — how far do the pins extend for a
  given lever throw, with technical drawings and the math.
- [The gearing math]({{ 'gearing-math/' | relative_url }}) — module, tooth counts, why
  the 5:1 ratio falls out for free.
- [Why twelve pins?]({{ 'why-twelve-pins/' | relative_url }}) — divisor math and the
  base-12 elegance.
- [The combination lock]({{ 'combination-lock/' | relative_url }}) — watchmaker-scale
  three-wheel mechanism in a 0.75" × 0.5" brass cage.
- [The hinge and frame]({{ 'hinge-and-frame/' | relative_url }}) — heavy-door swing
  kinematics, the clearance problem CAD catches for free.
- [FDM design considerations]({{ 'fdm-variant/' | relative_url }}) — cylinders → hex
  stock, tolerances, layer orientation.
- [Sources]({{ 'sources/' | relative_url }}) — the videos, with timestamps.

## Get the files

| Variant | Onshape | MakerWorld | Printables | STEP |
| --- | --- | --- | --- | --- |
| Faithful | [open in Onshape ↗](https://cad.onshape.com/documents/eaf3e87c1faae12ad867b335/w/83a96bb8921d1af3abd7aecd/e/9db299b535aaeded5de5120c) | n/a (CAD study) | n/a (CAD study) | [in repo](https://github.com/jmcpheron/vault-study/blob/main/step-source/faithful-vault.step) |
| FDM | [open in Onshape ↗](https://cad.onshape.com/documents/017898deda56c430272a5497/w/5d7667d0936a708006b152fa/e/8e68069be3521bc23b864206) | _(soon)_ | _(soon)_ | [in repo](https://github.com/jmcpheron/vault-study/blob/main/step-source/fdm-vault.step) |

## Credit

The mechanism design, the proportions, the gear math — all
[Adam Savage](https://www.tested.com/)'s work on the Tested YouTube
channel. This site is an independent CAD reinterpretation for
educational and hobby purposes. Full attribution in
[ACKNOWLEDGMENTS.md](https://github.com/jmcpheron/vault-study/blob/main/ACKNOWLEDGMENTS.md).

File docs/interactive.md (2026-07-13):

---
title: Interactive mechanism
---

# Interactive mechanism

Drag the slider. The 120-tooth ring gear rotates; the twelve 24-tooth
spur gears counter-rotate at five times the ring's angular speed
(120 ÷ 24 = 5); the twelve rack-and-pin assemblies translate radially
outward through the door body's pin bores into the frame.

<style>
.vault-controls {
  display: flex;
  flex-wrap: wrap;
  gap: 1.2em;
  align-items: center;
  justify-content: center;
  margin: 1em auto;
  max-width: 640px;
  font-family: -apple-system, BlinkMacSystemFont, sans-serif;
}
.vault-controls label { display: flex; align-items: center; gap: 0.4em; }
.vault-controls input[type="range"] { width: 200px; }
.vault-readout {
  font-variant-numeric: tabular-nums;
  font-weight: 600;
  min-width: 5ch;
  text-align: right;
}
#mechanism-svg {
  display: block;
  margin: 0 auto;
  max-width: 100%;
  height: auto;
}
</style>

<div class="vault-controls">
  <label>
    Ring rotation:
    <input type="range" id="ring-angle-slider"
           min="-15" max="15" step="0.1" value="0">
    <span id="ring-angle-readout" class="vault-readout">0.0°</span>
  </label>
  <label>
    Pin extension:
    <span id="pin-readout" class="vault-readout">0.00 mm</span>
  </label>
  <label>
    <input type="checkbox" id="bcd-toggle">
    Show 72 mm BCD (Adam's measured)
  </label>
</div>

{% include mechanism-interactive.svg %}

<script src="{{ '/assets/interactive.js' | relative_url }}" defer></script>

## What the controls do

- **Ring rotation slider** — between −15° and +15° of ring rotation.
  Each spur counter-rotates by 5× that amount (the 5 : 1 ratio
  derived in [the gearing math page]({{ '/gearing-math/' | relative_url }})). Each rack
  translates radially outward by `θ × r_pitch` mm, where `r_pitch` is
  the spur's pitch radius (6 mm for our 24-tooth, module-0.5 spurs).
- **Pin extension** — the live readout shows the linear distance each
  rack-and-pin assembly has moved from rest. Clamped to ±8 mm so
  extreme slider values don't push the pins off-screen.
- **Show 72 mm BCD** — swaps the spur centres from their
  gear-math-derived position (24 mm from door centre, where teeth
  actually mesh) to Adam's video-measured 72 mm bolt-circle (36 mm
  radius). At the measured BCD, the spurs are noticeably outside the
  ring's pitch circle — the discrepancy is real, and discussed in
  [the mechanics overview]({{ '/mechanics/' | relative_url }}#the-12-spur-crowding-question)
  and [`specs.md`](https://github.com/jmcpheron/vault-study/blob/main/specs.md#derived-values).

## How this page is built

The SVG above is generated by Python from the canonical parameters in
[`src/vaultkit/params.py`](https://github.com/jmcpheron/vault-study/blob/main/src/vaultkit/params.py)
plus [`src/vaultkit/gears.py`](https://github.com/jmcpheron/vault-study/blob/main/src/vaultkit/gears.py).
The generator lives in
[`src/vaultkit/explainers/schematic.py`](https://github.com/jmcpheron/vault-study/blob/main/src/vaultkit/explainers/schematic.py)
and is re-run by `vaultkit explain render`. The animation logic is
entirely client-side vanilla JavaScript in
[`docs/assets/interactive.js`](https://github.com/jmcpheron/vault-study/blob/main/docs/assets/interactive.js)
— no framework, no build step.

To regenerate after a parameter change:

```bash
vaultkit explain render
```

Then commit the regenerated `docs/_includes/mechanism-interactive.svg`.

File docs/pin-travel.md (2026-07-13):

---
title: Pin travel — how far do they go?
---

# Pin travel — how far do they go?

Turn the lever 15°. How far does each pin extend? Eyeballing the
[cam-sweep animation]({{ '/' | relative_url }}), it's a few millimetres — but how
few, and why? This page walks the math.

<p style="text-align:center; margin: 1.5em 0;">
  Top-down technical drawing of the vault mechanism showing the ring gear pitch diameter (Ø60), spur bolt-circle diameter (Ø72), pin diameter (Ø10), tooth counts (120 ring teeth, 24 spur teeth × 12 spurs), 30° spur spacing, and module 0.5.
</p>

## The rack-and-pinion identity

Imagine unrolling the spur gear's pitch circle into a straight line.
One full rotation unrolls into 2π·r of circumference, where r is the
pitch radius. The rack rides on that unrolled line — so if the spur
spins by θ radians, the rack travels exactly:

```
linear_travel = θ · r
```

That's it. The rack-and-pinion identity. No magic, just an unrolled
circle.

<style>
.pt-controls {
  display: flex;
  flex-wrap: wrap;
  gap: 1.2em;
  align-items: center;
  justify-content: center;
  margin: 1em auto;
  max-width: 640px;
  font-family: -apple-system, system-ui, sans-serif;
}
.pt-controls label { display: flex; align-items: center; gap: 0.4em; }
.pt-controls input[type="range"] { width: 220px; }
.pt-readout {
  font-variant-numeric: tabular-nums;
  font-weight: 600;
  min-width: 6ch;
  text-align: right;
}
#pt-svg {
  display: block;
  margin: 0 auto;
  max-width: 100%;
  height: auto;
}
.pt-math-table {
  margin: 1em auto;
  border-collapse: collapse;
  font-variant-numeric: tabular-nums;
}
.pt-math-table th, .pt-math-table td {
  padding: 0.35em 1em;
  border-bottom: 1px solid #e1e4e8;
  text-align: right;
}
.pt-math-table th { text-align: left; color: #586069; font-weight: 600; }
.pt-math-table tr.highlight td { background: #fff5ee; font-weight: 600; }
</style>

<div class="pt-controls">
  <label>Ring rotation:
    <input type="range" id="pt-slider" min="-15" max="15" step="0.1" value="0">
    <span id="pt-angle-readout" class="pt-readout">0.0°</span>
  </label>
  <label>Pin extension:
    <span id="pt-readout" class="pt-readout">0.00 mm</span>
  </label>
</div>

{% include pin-travel-closeup.svg %}

<script>
(function () {
  const SPUR_PITCH_RADIUS_MM = 6.0;
  const RATIO = 5.0;
  const CLAMP_MM = 12.0;

  const slider = document.getElementById('pt-slider');
  const angleR = document.getElementById('pt-angle-readout');
  const pinR   = document.getElementById('pt-readout');
  const rack   = document.getElementById('pt-rackpin');
  const dimT   = document.getElementById('pt-active-dim');
  if (!slider || !rack) return;

  function update() {
    const thetaDeg = parseFloat(slider.value);
    const thetaRad = thetaDeg * Math.PI / 180;
    const dr = thetaRad * RATIO * SPUR_PITCH_RADIUS_MM;
    const drVis = Math.max(-CLAMP_MM * 0.7, Math.min(CLAMP_MM * 0.7, dr));
    rack.setAttribute('transform', 'translate(' + drVis + ' 0)');
    if (angleR) angleR.textContent = thetaDeg.toFixed(1) + '°';
    if (pinR)   pinR.textContent = dr.toFixed(2) + ' mm';
    if (dimT)   dimT.textContent = 'Δr = ' + dr.toFixed(2) + ' mm';
  }
  slider.addEventListener('input', update);
  update();
})();
</script>

The orange dashed line in the close-up marks where the rack runs out
of teeth — roughly 12 mm of engaged travel before the last rack tooth
disengages from the spur. We'll come back to that.

## Plug in the vault numbers

The vault has **module 0.5** gears. The 24-tooth spur has a pitch
diameter of `0.5 × 24 = 12 mm`, so its pitch radius is `r = 6 mm`.

The ring (driver) has 120 teeth; the spur (driven) has 24. The ratio
is `120 / 24 = 5` — every full turn of the ring drives each spur
five full turns.

Chaining the two: if the **ring** rotates by θ radians, each spur
rotates by `5θ` radians, and the rack (driven by the spur) travels:

```
pin_travel_mm = (5 · θ_ring_rad) · r_spur_pitch
              = 5 · θ_ring_rad · 6 mm
              = 30 · θ_ring_rad
```

Thirty millimetres of pin travel per radian of ring rotation. Convert
to degrees:

```
pin_travel_mm = 30 · (π / 180) · θ_ring_deg
              ≈ 0.524 · θ_ring_deg
```

About **half a millimetre of pin extension per degree of ring
rotation**. The reciprocal — about **1.91° of ring rotation per
millimetre of pin extension** — is the useful number if you're
designing a lever's mechanical advantage.

## How that lands at typical lever angles

<table class="pt-math-table">
  <thead><tr><th>Ring rotation</th><th>Pin travel</th></tr></thead>
  <tbody>
    <tr><td>5°</td><td>2.62 mm</td></tr>
    <tr><td>10°</td><td>5.24 mm</td></tr>
    <tr class="highlight"><td>15°</td><td>7.85 mm</td></tr>
    <tr><td>20°</td><td>10.47 mm</td></tr>
    <tr><td>22.9°</td><td>12.00 mm  <em>(rack disengages)</em></td></tr>
    <tr><td>30°</td><td>15.71 mm  <em>(over-travel)</em></td></tr>
    <tr><td>45°</td><td>23.56 mm  <em>(way over-travel)</em></td></tr>
  </tbody>
</table>

The realistic operating range — between the resting position and the
rack's disengagement point — is a ring angle of about ±22°. Adam's
build doesn't show a clean lever-stop angle on camera, but a 15°
throw landing the pins at ~7.85 mm of extension feels about right for
the geometry: that's ~65% of available stroke, well within the
mechanism's design range.

<p style="text-align:center; margin: 1.5em 0;">
  A single locking pin shown in two positions: at rest (light grey) inside the door body bore, and after a 15° lever throw (dark) extended into the frame receiver. The travel between the two positions is 7.85 mm.
</p>

## Sanity check

The pins are 30 mm long. With 7.85 mm of travel from a 15° throw,
the pin starts proud at rest and ends well into the frame receivers.
Plenty of engagement, plenty of margin before the rack disengages.
The numbers fit the design.

## What about the FDM variant?

It's the same. The kinematic identities are **gear-math invariants**
— they depend only on the module, the tooth counts, and the ratio.
The FDM redesign swaps cylinders for hex stock and adjusts
tolerances for printer realities, but it preserves the gears. So
every number on this page applies identically to the FDM build. See
[the FDM design considerations]({{ '/fdm-variant/' | relative_url }}) for what *does*
change.

## See also

- [The gearing math]({{ '/gearing-math/' | relative_url }}) — where the 5:1 ratio comes
  from and why module matters more than diameter.
- [Interactive mechanism]({{ '/interactive/' | relative_url }}) — the full assembly,
  driven by a slider. This page is the math behind that demo.
- [Mechanics overview]({{ '/mechanics/' | relative_url }}) — the whole power chain from
  dial to pins.

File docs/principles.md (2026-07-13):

---
title: What this project believes
---

# What this project believes

Five things. We try to live by them in the code, in the diagrams,
and in the prose. If any page on this site contradicts one, file an
issue — we'd rather fix it than be wrong about it.

## Parametric beats screenshot

Every dimension in this project lives in **one Python file**
([`src/vaultkit/params.py`](https://github.com/jmcpheron/vault-study/blob/main/src/vaultkit/params.py)).
Change `PIN_DIAMETER_MM` from 10 to 12 and the whole site rebuilds:
the SVG schematics shift, the OpenSCAD animations re-render, the
explainer pages quote the new number, the drift test makes sure
nothing in `specs.md` got missed. Screenshots lie about what a
project actually is at any given moment; parameters don't.

## Hands-on beats documentation

A slider that drives twelve gears teaches the mechanism in three
seconds. Three paragraphs about gear ratios teach it in three
minutes — and only to readers who finish them. So our hero is
[the interactive demo]({{ '/interactive/' | relative_url }}), not the prose. The prose
is for after you've grabbed the slider.

## Two variants, one mechanism

Adam Savage's machined vault and our FDM-printable redesign share
the same 120-tooth ring, twelve 24-tooth spurs, twelve pins, and a
combination-lock-as-gatekeeper. They differ in everything else —
cast iron vs PETG, side-bored cylinders vs hex-stock anti-rotation,
0.020-inch machined fits vs slicer-tested clearances. The
[mechanism stays the same]({{ '/mechanics/' | relative_url }}); the
[manufacturing language]({{ '/faithful-vs-fdm/' | relative_url }}) changes.

## The discrepancies are the lessons

When the gear math derives a 24 mm spur radius and Adam measured a
36 mm one, we don't pick a side and quietly delete the other. The
[interactive page]({{ '/interactive/' | relative_url }}) has a checkbox that flips
between them, and the math behind both gets its own page. The
disagreement is more interesting than either resolution. We learn
the most from the things that don't quite line up.

## Credit Adam

The mechanism design, the 120-tooth ring, the 5:1 ratio, the
combination-lock-as-gatekeeper coupling — that's all
[Adam Savage](https://www.tested.com/)'s work on the Tested YouTube
channel. This site is an independent CAD reinterpretation for
educational and hobby purposes. The **geometry** is CC BY-SA 4.0
(share-alike); the **code** that processes it is MIT. Both are
linked from the [repo](https://github.com/jmcpheron/vault-study).
We try to link to Adam's videos every time we cite him. He's the
reason this project exists.

---

The contributor-facing style guide lives at
[`STYLE.md`](https://github.com/jmcpheron/vault-study/blob/main/STYLE.md).
It's where the editorial rules behind these principles get spelled
out for anyone writing code or prose for this repo.

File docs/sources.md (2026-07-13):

---
title: Sources
---

# Sources

The vault project is a study of **Adam Savage's** miniature
bank-vault-door build, shown on the
[Tested YouTube channel](https://www.tested.com/). The videos are
the original work; this site is commentary.

## The build series

| Part | Topic | Tag in [`specs.md`](https://github.com/jmcpheron/vault-study/blob/main/specs.md) |
| --- | --- | --- |
| 1 | [Ring gear machining](https://www.youtube.com/watch?v=SiL8IzJSnyU) | `[part-1]` |
| 2 | Locking pins, racks, main door body | `[part-2]` |
| 3 | Vault door (heavy puck), frame, hinge | `[part-3]` |
| 4 | Concentricity, rack refinement, pin-diameter revision | `[part-4]` |
| 5 | Combination lock | `[part-5]` |

_(Direct URLs for parts 2–5 — to be added.)_

## How sources cascade into the repo

```
Adam's video        →  specs.md                 (canonical, source-tagged)
   mirrored         →  src/vaultkit/params.py   (code-readable)
   tested           →  tests/test_no_drift.py   (drift check)
   explained        →  docs/*.md                (this site + the blog posts)
```

Every number on every page should trace back through that chain to
a `[part-N]` tag in `specs.md` to a timestamp in one of Adam's
videos.

## Attribution

The mechanism design — 12 pins, 120/24 gear math, combination-lock
gatekeeper, rack-and-pinion linear motion, the geometry of the
hinge — is Adam's. This repo is an independent CAD reinterpretation
for educational and hobby purposes, licensed CC BY-SA 4.0 (see
[`LICENSE-3D-FILES`](https://github.com/jmcpheron/vault-study/blob/main/LICENSE-3D-FILES)).

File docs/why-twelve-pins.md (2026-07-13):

---
title: Why twelve pins?
---

# Why twelve pins?

_(Stub — to be written. Goal: trace the divisor math, explain why a
real vault uses 24, why halving works at 1/12 scale, and how base-12
elegance shows up in the dividing-plate fixture Adam already owns.)_

For the divisor rule itself, see
[the gearing math page]({{ '/gearing-math/' | relative_url }}#timing-120--12--10).

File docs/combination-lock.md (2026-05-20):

---
title: The combination lock
---

# The combination lock

_(Stub — to be written. Goal: explain the watchmaker-scale 3-wheel
mechanism in the 0.75" × 0.5" brass cage, the drive-tab / locking-slot
geometry of each 0.450" wheel, the 36-division dial math, and the
bell-crank linkage that couples drop-arm release to ring-gear
rotation.)_

For dimensions, see
[`specs.md` → Combination lock](https://github.com/jmcpheron/vault-study/blob/main/specs.md#combination-lock).

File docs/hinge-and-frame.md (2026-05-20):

---
title: The hinge and frame
---

# The hinge and frame

_(Stub — to be written. Goal: cover the 3/8" thrust-bearing stack on
a 1/8" pin, the 28-screw M2 mounting pattern, and the door-clearance
kinematics problem Adam discovered only after machining — and that
CAD catches for free via interference detection.)_

For dimensions, see
[`specs.md` → Hinge](https://github.com/jmcpheron/vault-study/blob/main/specs.md#hinge)
and
[`specs.md` → Door frame](https://github.com/jmcpheron/vault-study/blob/main/specs.md#door-frame).

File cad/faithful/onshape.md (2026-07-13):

# Onshape working notes — faithful variant

CAD-tool-specific guidance for the faithful build. [`../../specs.md`](../../specs.md)
is for *what* to model; this file is for *how* to model it in Onshape.

Absorbed and expanded from the original YouTube scratch notes
(since removed) and their per-video "Tips for Modeling this in
Onshape" sections.

## Variables at the top of the Part Studio

Every parameter in [`../../src/vaultkit/params.py`](../../src/vaultkit/params.py)
should also be defined as an Onshape variable at the top of the
Part Studio, using the same name (in Onshape's `#snake_case` form).
The Onshape variables are the editing surface; `params.py` is the
diffable record. They are kept in sync **by hand** until automation
lands.

Example: `#PIN_DIAMETER_MM = 10 mm` drives every radial bore in
both the acrylic hub and the cast-iron puck. Change the variable,
the whole model re-derives.

## FeatureScripts

Don't hand-draw involute gear teeth — the standard custom-feature
library has a **Spur Gear** generator. Add it via "Add custom
features" in any Part Studio.

| Gear | Settings |
| --- | --- |
| Spur gear (qty 12) | Module 0.5, 24 teeth |
| Ring gear | Module 0.5, 120 teeth, **Internal Gear** option |

The 2.4-in outer-diameter target on the ring gear should fall out
of the math once module and tooth count are right; verify against
[`../../specs.md`](../../specs.md) after generating.

## Assembly: getting them to mesh

1. **Revolute Mate** each spur gear and the ring gear to the
   acrylic hub so each rotates about its axis.
2. **Gear Relation** between the ring gear and *one* spur gear.
   Onshape derives the 5:1 ratio from the tooth counts automatically.
3. For the locking pins, **Slider Mate** the pin radially through
   the hub, then **Rack and Pinion Relation** between the spur's
   Revolute Mate and the pin's Slider Mate. Drive the ring gear
   and watch the pin extend. Check the **Limits** box on the Slider
   Mate and set the maximum travel to the length of the rack's
   toothed section — the pin then hits a hard stop when it runs out
   of teeth, just like the real one.
4. **Circular Assembly Pattern** the perfectly-mated single
   spur+pin assembly 12 times around 360° at 30° intervals. This
   is the CAD answer to Adam's "all 12 racks must be machined
   identically" problem — Onshape mathematically guarantees it.

## The rack relief cut (Boolean Subtract)

The backs of the 8 mm square racks sit so close to the ring gear
that Adam scoops a curved relief into each one. Don't guess the
curve: place the racks in the assembly around the ring gear, then
in the Part Studio use a **Boolean** feature set to **Subtract**
with a cylinder slightly larger than the ring gear as the tool.
Onshape carves the exact clearance curve for free.

## Sub-assemblies (recommended)

Build one (spur + rack + pin) as its own Assembly tab, fully mated,
fully timed. Insert that sub-assembly 12 times into the main vault
assembly. Keeps the mate tree clean.

## Door swing kinematics

Once the heavy puck, frame, and hinge are modelled (see
[`../../specs.md`](../../specs.md) → Hinge section), Revolute Mate the
door to the hinge pin and **drag the door open with the mouse**.
Use Onshape's **Interference Detection** to check whether the back
edge of the puck clips the aluminum frame at any angle. This is the
issue Adam discovered only after machining — CAD catches it for
free.

## Combination lock as a sub-assembly

Build the 0.75 in × 0.5 in cage as a completely separate Assembly
tab. Get the three 0.450 in wheels, the cage, and the 1/8 in
spindle perfectly aligned, then insert that sub-assembly into the
main vault. Use **Tangent Mates** or limit constraints to simulate
the drive-tab "drag" between adjacent wheels.

## Gotchas & lessons learned

_(Add entries here as you run into them.)_

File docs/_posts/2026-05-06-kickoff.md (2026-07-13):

---
title: "Why we're rebuilding Adam Savage's vault door in CAD"
date: 2026-05-06 09:00:00 -0700
excerpt: >
  One ring gear, twelve spur gears, twelve locking pins, all timed off
  tooth counts you can verify by pausing the video. We're rebuilding
  Adam Savage's 1/12-scale vault door in Onshape, in public.
---

# Why we're rebuilding Adam Savage's vault door in CAD

We watched Adam Savage machine a 1/12-scale bank-vault door on his
Tested YouTube series and couldn't stop thinking about the mechanism:
one 120-tooth ring gear, twelve 24-tooth spur gears, twelve locking
pins, all timed off tooth counts you can verify by pausing the video.
So we're rebuilding it in Onshape, in public.

The pull is that this mechanism is *legible*. Most lock mechanisms
hide their cleverness; this one wears it. Turn the ring gear and
twelve rack-and-pinions shoot twelve pins radially outward in
perfect unison — and the reason they stay in unison is arithmetic,
not craftsmanship: 120 divides by 12, so every spur gear sees the
same ten teeth of ring gear between neighbours. Adam has to *machine*
that identically twelve times. We get it for free with a circular
pattern, which feels like cheating and is exactly why it's a good
first assemblies project.

What we want to learn, concretely: Onshape assemblies end-to-end —
gear relations, rack-and-pinion mates, sub-assembly patterns, and
the discipline of driving a whole model from a variable sheet.

What "done" looks like, in two acts:

1. **A public Onshape document anyone can open** and drag the
   mechanism around in — [it's live now ↗](https://cad.onshape.com/documents/eaf3e87c1faae12ad867b335/w/83a96bb8921d1af3abd7aecd/e/9db299b535aaeded5de5120c),
   in whatever half-built state we've left it.
2. **An FDM-printable conversion** — same mechanism, redesigned for
   a desktop printer, ending as a 3MF bundle anyone can print.

What we're intentionally not doing: machining one. Adam already did,
and better than we would — start with
[part 1 of his series ↗](https://www.youtube.com/watch?v=SiL8IzJSnyU)
(the rest are on the [sources]({{ 'sources/' | relative_url }}) page).
The vault is his design; this study is our homework on it.

If you'd rather poke the mechanism than read about it, the
[interactive demo]({{ 'interactive/' | relative_url }}) is the place
to start.

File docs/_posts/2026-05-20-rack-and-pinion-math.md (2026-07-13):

---
title: "Half a millimetre per degree: the pin-travel math"
date: 2026-05-20 09:00:00 -0700
excerpt: >
  Turn the ring gear one degree and every pin extends 0.524 mm. The
  whole chain — lever to ring to spur to rack to pin — reduces to one
  identity and one ratio, and we drew the technical drawings to prove it.
---

# Half a millimetre per degree: the pin-travel math

Turn the ring gear one degree and every pin extends 0.524 mm. The
whole chain — lever to ring to spur to rack to pin — reduces to one
identity and one ratio, and this post walks both.

<p style="text-align:center; margin: 1.5em 0;">
  Top-down technical drawing of the vault mechanism: ring gear pitch diameter Ø60, spur bolt-circle Ø72, pin diameter Ø10, 120 ring teeth, 24-tooth spurs at 30° spacing.
</p>

The identity is the rack-and-pinion one: unroll a spur gear's pitch
circle into a straight line and a rotation of θ radians becomes a
linear travel of exactly `θ · r`. No approximation — an unrolled
circle is the definition of a radian.

The ratio comes from the tooth counts. The 120-tooth ring gear
drives twelve 24-tooth spurs, so each spur turns 120/24 = 5 times
per ring revolution. Chain the two together with the spur's 6 mm
pitch radius (module 0.5 × 24 teeth / 2) and:

```
pin_travel = θ_ring · 5 · 6 mm  ≈  0.524 mm per ring degree
```

At the 15° lever throw we use everywhere on this site, that's
**7.85 mm of pin extension** — enough to bury a pin well past the
0.020" door-frame gap and into its receiver.

## Where the drawing earns its keep

<p style="text-align:center; margin: 1.5em 0;">
  Close-up technical drawing of one spur gear meshing with one rack: 6 mm pitch radius, 1.57 mm tooth pitch, pitch point marked, rack-disengagement limit flagged.
</p>

The close-up also shows the limit: the rack has a finite toothed
section, and past about 12 mm of travel — a 22.9° ring throw — the
spur runs out of rack. That's not a number we invented; it falls
out of `θ · r` run backwards from the rack length.

<p style="text-align:center; margin: 1.5em 0;">
  Technical drawing of one pin at rest and after a 15° ring throw, extended 7.85 mm through the door body into the frame receiver.
</p>

The full derivation — with a slider you can drag and the table of
travel per lever angle — lives on the evergreen
[pin travel]({{ '/pin-travel/' | relative_url }}) page; the
[gearing math]({{ '/gearing-math/' | relative_url }}) page covers
where the 5:1 comes from. This post is the story; those pages are
the math.

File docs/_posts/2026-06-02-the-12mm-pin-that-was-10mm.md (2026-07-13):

---
title: "The 12 mm pin that turned out to be 10 mm"
date: 2026-06-02 09:00:00 -0700
excerpt: >
  In part 2 of the build series, Adam's drawing calls for 12 mm locking
  pins. In part 4, he picks one up and calls it 10 mm. A canonical
  number changed mid-series — which is exactly the situation parametric
  CAD is built for.
---

# The 12 mm pin that turned out to be 10 mm

In [part 2 of the build series](https://www.tested.com/), Adam's
technical drawing calls for 12 mm locking pins. In part 4, he picks
one up on camera and calls it 10 mm. A canonical number changed
mid-series — which is exactly the situation parametric CAD is built
for.

Our [`specs.md`](https://github.com/jmcpheron/vault-study/blob/main/specs.md)
keeps both rows: the 12 mm value struck through and marked
superseded, the 10 mm value tagged `[part-4]`. We could have
silently edited the number, but the strikethrough *is* the lesson.
Dimensions sourced from a video series are measurements of a moving
target, and the honest record shows its revisions.

The mechanical ripple is the interesting part. The pin diameter
drives the twelve radial bores in the acrylic hub, the twelve bores
in the cast-iron puck, and (in our FDM variant) the hex-stock
cross-section that replaces the cylinder. In Onshape that's one
variable — change `#PIN_DIAMETER_MM` and the model re-derives. In
the repo it's one constant, `PIN_DIAMETER_MM` in
[`params.py`](https://github.com/jmcpheron/vault-study/blob/main/src/vaultkit/params.py),
and a drift test fails CI if `specs.md` and the code ever disagree.
One number, one diff, every dependent dimension follows:

<p style="text-align:center; margin: 1.5em 0;">
  Top-down technical drawing of the mechanism with the Ø10 pin callout — the revised diameter, not the original 12 mm.
</p>

Part 4 is also where Adam pays for the physical version of this
change. The racks screw into the pins on threaded studs he first
cut by hand with a die, and hand-cut threads came out about 0.0125"
off-center. Screwed together, the racks sat sideways and the pins
bound in their bores. His fix is a lovely piece of shop discipline:
an 8 mm square 5C collet to hold the stock dead-center, a depth
stop so every rack protrudes identically, and the die held in the
lathe's tailstock so the thread can only go on straight. He also
machines **14 racks for 12 slots** — "always make more than you
need," because assumptions kill.

We get all of that for free with a circular pattern, which is worth
being honest about: the CAD version of this project skips the
hardest parts. What we keep is the arithmetic — and the reminder
that a 0.0125" error was enough to jam the mechanism. That number
comes back in a later post, where we run the same stack-up math
forward for the printed version.

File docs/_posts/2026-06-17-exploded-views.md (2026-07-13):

---
title: "Exploding the vault: animated views from the STEP file"
date: 2026-06-17 09:00:00 -0700
excerpt: >
  The FDM variant, pulled apart along its assembly axis: one body
  plate, one ring gear, twelve spur-and-rack sets. The exploded view
  is generated straight from the STEP export, so it can never drift
  from the actual model.
---

# Exploding the vault: animated views from the STEP file

The FDM variant, pulled apart along its assembly axis: one body
plate, one ring gear, twelve spur-and-rack sets. The exploded view
is generated straight from the STEP export, so it can never drift
from the actual model.

<p style="text-align:center; margin: 1.5em 0;">
  <picture>
    <source srcset="{{ '/assets/generated/mechanism-exploded-fdm.webp' | relative_url }}" type="image/webp">
    Exploded-view animation of the FDM vault mechanism: the ring gear and twelve spur-and-rack sets lift away from the body plate and reassemble.
  </picture>
</p>

What the explosion makes obvious that the assembled view hides:

- **The part count is honest.** One plate, one ring, and twelve
  copies of the same three-part satellite. If you can print one
  spur-and-rack set that works, you can print the whole door.
- **The assembly order is forced.** The ring gear has to land in
  the central cavity before any satellite goes in, because the
  racks trap it radially. The animation is accidentally an
  assembly manual.
- **Everything stacks along one axis.** That's the FDM redesign
  doing its job — every part lies flat on the build plate, and the
  whole mechanism assembles by dropping parts straight down.

## The mechanism in motion

The companion animation sweeps the cam through its throw — the
same 15° that the [pin-travel math]({{ '/pin-travel/' | relative_url }})
converts to 7.85 mm of pin extension:

<p style="text-align:center; margin: 1.5em 0;">
  <picture>
    <source srcset="{{ '/assets/generated/mechanism-cam-sweep-fdm.webp' | relative_url }}" type="image/webp">
    Cam-sweep animation of the FDM vault mechanism: the ring gear oscillates and twelve pins extend and retract in unison.
  </picture>
</p>

## Faithful vs FDM, one frame each

Side by side, the two variants' current states — the faithful puck
still blocky, the FDM plate further along:

<p style="text-align:center; margin: 1.5em 0;">
  Isometric render of the faithful variant: a solid puck with side-bored pin holes.
  Isometric render of the FDM variant: a thin plate with twelve radial bays.
</p>

The [faithful vs FDM]({{ '/faithful-vs-fdm/' | relative_url }})
page holds the full STEP-level diff — bounding boxes, entity
histograms, and why the FDM file is the more developed of the two.

How these are made, in one paragraph: the STEP export from Onshape
gets pulled apart into named parts, each part is tessellated to
STL, and an OpenSCAD template animates the stack — all driven by
the repo's Python tooling (the
[README](https://github.com/jmcpheron/vault-study#readme) has the
pipeline). The point of the plumbing is that none of these images
are drawn by hand; re-export the STEP and every view regenerates.

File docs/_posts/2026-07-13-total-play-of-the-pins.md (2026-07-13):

---
title: "How much do the pins actually rattle? A tolerance stack-up"
date: 2026-07-13 00:00:00 +0000
excerpt: >
  A printed Ø10 pin in a Ø10.4 bore has 0.2 mm of radial slop — but how
  much can the pin tip really move, and how far can the locked door
  shift before the pins catch it? We ran the stack-up, faithful vs FDM.
---

# How much do the pins actually rattle? A tolerance stack-up

A printed Ø10 pin in a Ø10.4 bore has 0.2 mm of radial slop — but
how much can the pin tip really move, and how far can the locked
door shift before the pins catch it? We ran the stack-up for both
variants, and every number below comes out of the repo's math
kernel, not out of our heads.

<p style="text-align:center; margin: 1.5em 0;">
  Cross-section technical drawing of one Ø10 locking pin extended through a Ø10.4 door bore into the frame receiver, showing the 0.2 mm radial clearance, the 0.508 mm door-frame gap, and the 1.03° maximum tilt, with clearances exaggerated 10× for visibility.
</p>

## The fits

The faithful variant's pins ride in machined, reamed bores — Adam's
slip fit. We model that clearance as zero (a real slip fit is a few
hundredths of a millimetre; we don't have his reamer chart, so zero
plus a hedge is more honest than a guessed decimal). The FDM
variant can't play that game: printed bores need real clearance or
the pin fuses to the door. The planned bore from
[`cad/fdm/deviations.md`](https://github.com/jmcpheron/vault-study/blob/main/cad/fdm/deviations.md)
is **10.4 mm for the 10 mm pin** — 0.4 mm diametral, 0.2 mm radial,
still TBD until we tune it on an actual print.

## The stack-up

At the standard 15° lever throw (7.85 mm of pin extension — see
[pin travel]({{ '/pin-travel/' | relative_url }})):

| | faithful | FDM |
| --- | ---: | ---: |
| Bore diameter | 10.000 mm | 10.400 mm |
| Diametral clearance | 0.000 mm | 0.400 mm |
| Radial clearance | 0.000 mm | 0.200 mm |
| Tilt at rest (30 mm guided) | 0.000° | 0.764° |
| Tilt extended (22.1 mm guided) | 0.000° | 1.035° |
| Lateral play at the pin tip | 0.000 mm | 0.351 mm |
| Locked-door play | 0.000 mm | 0.400 mm |
| Door-frame gap | 0.508 mm | 0.508 mm |

Three things in that table are worth unpacking.

**Tilt grows as the pin extends.** A pin can cock inside its bore
until it touches both walls: `atan(clearance / guided length)`. At
rest the full 30 mm of pin is guided and the FDM pin can tilt
0.764°. Extended 7.85 mm, only 22.1 mm remains in the bore and the
tilt grows to 1.035°. Project that tilt over the overhanging tip —
7.85 mm of extension plus the 0.508 mm door-frame gap — add the
0.2 mm of pure sideways float, and the FDM pin tip can wander
**0.351 mm** before anything stops it.

**The pins catch the door before the frame does.** Locked, each
pin bridges the door bore and the frame receiver. The door can
shift by the sum of the two radial clearances — 0.4 mm for the FDM
variant (assuming the receivers get the same fit as the door
bores) — before pins bear on both walls. That's *less* than the
0.508 mm door-frame gap, so in the printed vault the locking pins,
not the door rim, are what you feel when you shake the locked
door. In the faithful variant both numbers at the pin are zero,
and the 0.020" rim gap is the only play there is.

**Adam already ran this math in reverse.** In part 4, his
hand-threaded rack studs came out 0.0125" (0.318 mm) off-center —
comfortably inside our FDM clearance budget, but his bores had no
budget. In a near-zero-clearance slip fit, 0.318 mm of stud offset
is the whole stack-up spent on one error, and his pins bound
exactly the way the table predicts. Tight fits don't forgive;
that's what the 5C collet was for
(the [previous post]({{ '/2026/06/02/the-12mm-pin-that-was-10mm/' | relative_url }})
has that story).

## What we're not counting yet

Gear backlash. Every gear mesh has a dead-band, and a
rack-and-pinion passes it straight through to pin travel, 1:1. We
don't have a measured backlash figure for module-0.5 gears —
machined or printed — so it appears in the kernel as an input with
no default, not as a made-up constant. When the first FDM gears
come off the printer, we'll measure it, it becomes a `params.py`
number, and this table grows a row.

---

*The table is computed by
[`src/vaultkit/play.py`](https://github.com/jmcpheron/vault-study/blob/main/src/vaultkit/play.py)
from the canonical dimensions in
[`specs.md`](https://github.com/jmcpheron/vault-study/blob/main/specs.md) —
run `vaultkit play` to reproduce it. The diagram above is generated
from the same constants. See also
[faithful vs FDM]({{ '/faithful-vs-fdm/' | relative_url }}) for the
two variants' broader diff.*

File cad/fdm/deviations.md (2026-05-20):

# FDM deviations from the faithful variant

The single home for every "why is the FDM one different from Adam's
build?" answer. The two variants will drift. This is where the drift
is explained — not in commit messages, not in Slack, not in the
explainer pages alone.

Each entry: **what changed**, **why** (the manufacturing or
ergonomic reason), and **link to specs.md / params.py** if the change
touched a canonical number.

## Format

```markdown
### Short name of the change

**Parameter / part:** Which thing was modified.
**Faithful value:** What Adam's build uses.
**FDM value:** What this variant uses.
**Why:** The manufacturing or ergonomic reason.
**Trade-off:** What we gave up.
**Related:** Links to specs.md sections, deviations elsewhere, or the
explainer page that motivates the choice.
```

---

## Planned deviations (not yet implemented in the Onshape doc)

### Hex stock instead of cylinders for the rack stock

**Parameter / part:** Rack stock cross-section.
**Faithful value:** 8 mm × 8 mm square stock, M6 turned-down stud
(see [`../../specs.md`](../../specs.md) → "Racks").
**FDM value:** TBD — hexagonal or octagonal stock so the rack can't
spin in its bore without needing a keyway.
**Why:** FDM threaded studs are unreliable at this scale; we want
the rotational lock to come from geometry, not threads.
**Trade-off:** Slightly more complex slot in the door body.
**Related:** [`../../docs/fdm-variant.md`](../../docs/fdm-variant.md)

### Loosened pin-to-bore clearance

**Parameter / part:** Locking-pin radial bore.
**Faithful value:** 10 mm dia bore for a 10 mm pin (effectively
zero clearance — machined slip-fit, see
[`../../specs.md`](../../specs.md) → "Main door body").
**FDM value:** TBD — likely 10.4 mm bore for a 10 mm pin, tuned per
slicer + filament profile.
**Why:** FDM hole tolerances are stack-dependent and tighten on
cooling.
**Trade-off:** Pins rattle slightly when unlocked. Acceptable for a
hobby print.
**Related:** [`../../docs/fdm-variant.md`](../../docs/fdm-variant.md)

### Drop the hinge-and-frame assembly entirely (initial release)

**Parameter / part:** Hinge + aluminum frame.
**Faithful value:** Full multi-bearing hinge on a 1/2 in 6061
aluminum frame.
**FDM value:** First MakerWorld release ships just the round
mechanism puck; no hinge, no frame. Door sits on the table.
**Why:** Hinge requires hardware we don't want first-time printers
to source. Mechanism is the interesting bit.
**Trade-off:** Less complete as a display piece. Plan: hinge as a
v2 add-on.
**Related:** [`../../docs/fdm-variant.md`](../../docs/fdm-variant.md)

---

## Live deviations (in the FDM Onshape doc)

_(Move entries from "Planned" to "Live" as they land in the doc.
Currently empty — the FDM Onshape doc is still being built.)_

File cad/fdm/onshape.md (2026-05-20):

# Onshape working notes — FDM variant

Inherits from [`../faithful/onshape.md`](../faithful/onshape.md).
This file records the **deltas**: settings and mate strategies that
diverge from the faithful build because of FDM constraints.

When in doubt, follow the faithful conventions and document the
deviation here (and in [`deviations.md`](deviations.md)).

## Variables that differ from faithful

Track per-variable. As of bootstrap, all variables match the
faithful values; deltas land here when the FDM Onshape doc starts
diverging.

| Variable | Faithful | FDM | Why |
| --- | --- | --- | --- |
| _(none yet)_ | | | |

## FeatureScripts

Same Spur Gear FeatureScript as the faithful variant — the
mechanism's gear math is the part we explicitly *do not* change.

## FDM-specific modeling patterns

_(Filled in as decisions are made in the Onshape doc. Likely
entries:_

- Hex-stock substitution pattern for cylindrical parts that need
  anti-rotation (avoids printed keyways).
- Tolerance offsets — clearance-fit holes get extra dimension based
  on tested slicer + filament combination.
- Layer-orientation choice per-part, encoded as a part-attribute
  comment so the 3MF bundle can be assembled programmatically.
  _)_

## Gotchas & lessons learned

_(Add entries here as you run into them. FDM has its own catalog
of "wait, that doesn't work because…" — keep them findable.)_

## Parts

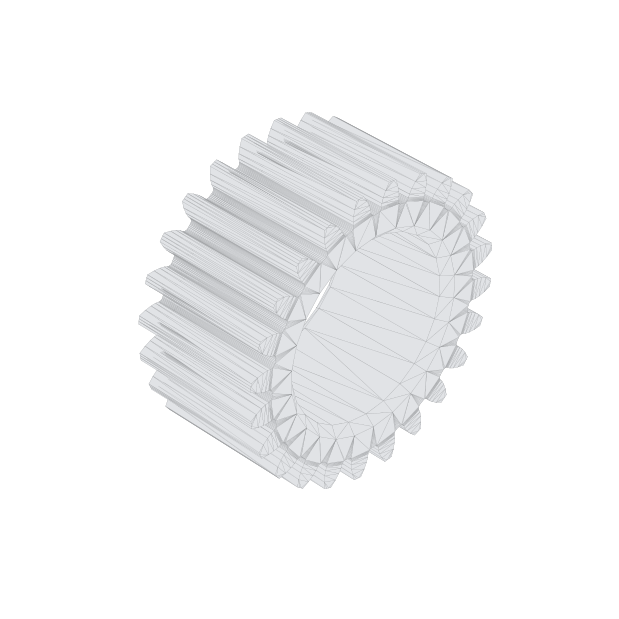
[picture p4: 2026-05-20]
docs/assets/generated/parts/faithful/spur-gear-24-teeth-0.iso.png

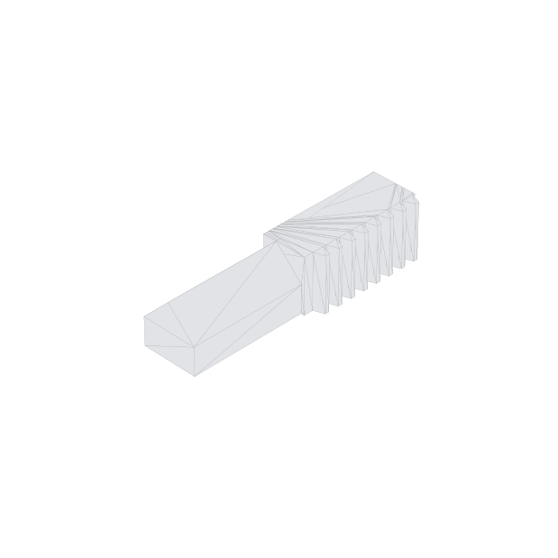
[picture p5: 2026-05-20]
docs/assets/generated/parts/fdm/part-1-0.iso.png

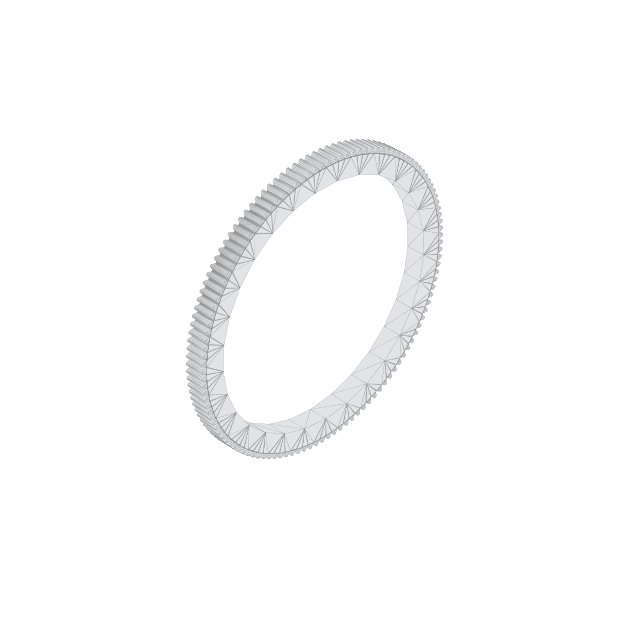
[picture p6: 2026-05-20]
docs/assets/generated/parts/faithful/spur-gear-120-teeth-2.iso.png

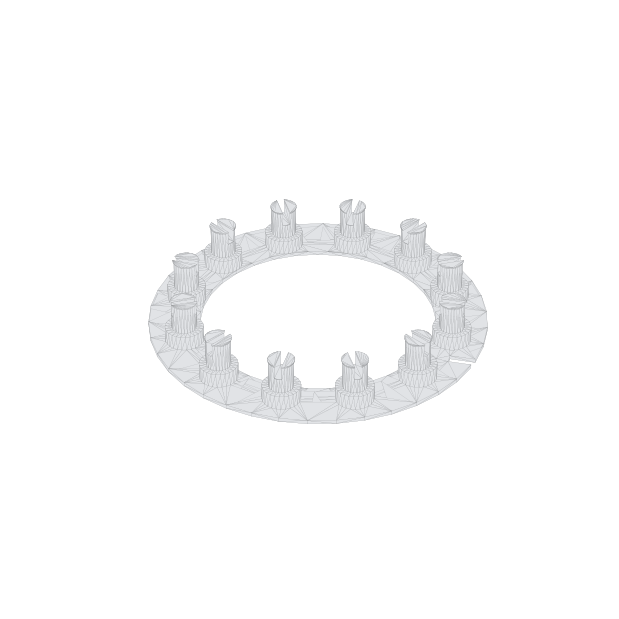
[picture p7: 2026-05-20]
docs/assets/generated/parts/fdm/part-1-5.iso.png

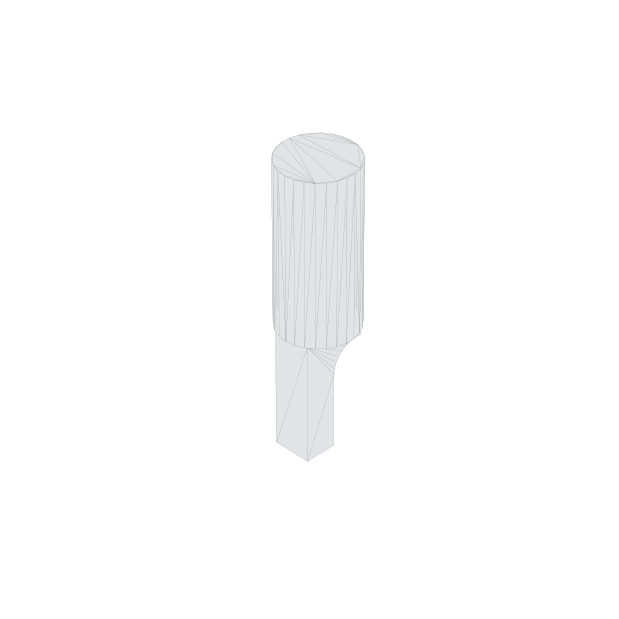
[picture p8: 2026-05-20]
docs/assets/generated/parts/faithful/part-1-1.iso.png

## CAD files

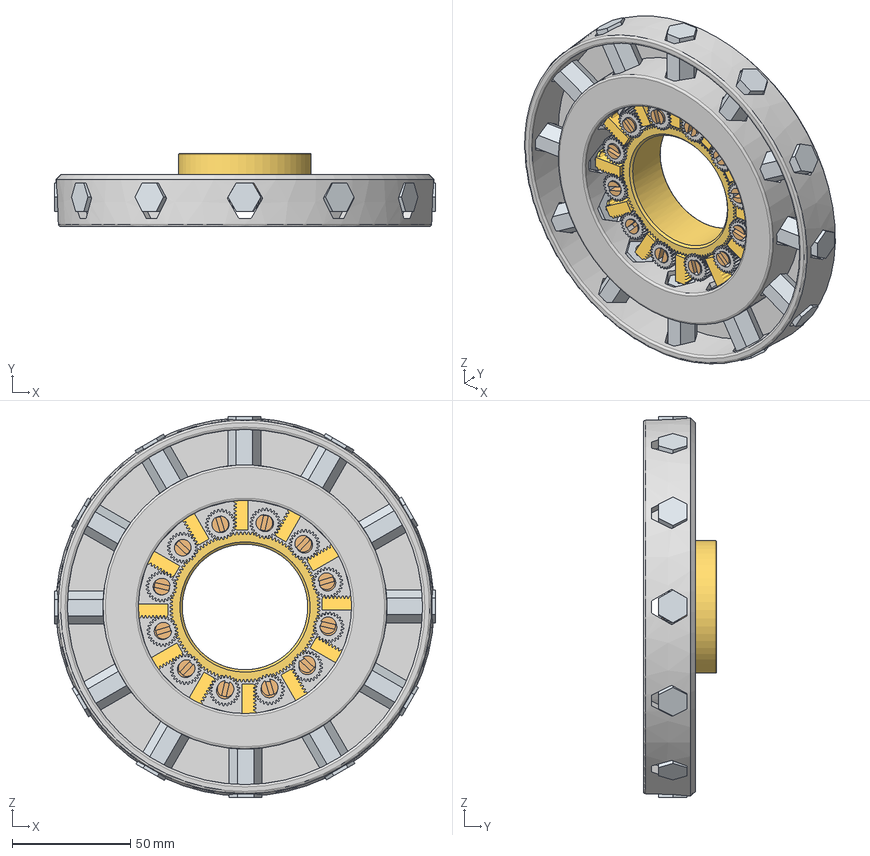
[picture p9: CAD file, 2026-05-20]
step-source/fdm-vault.step
160.9 x 31.0 x 160.9 mm
Spur gear (24 teeth) x 12
Spur gear (120 teeth)

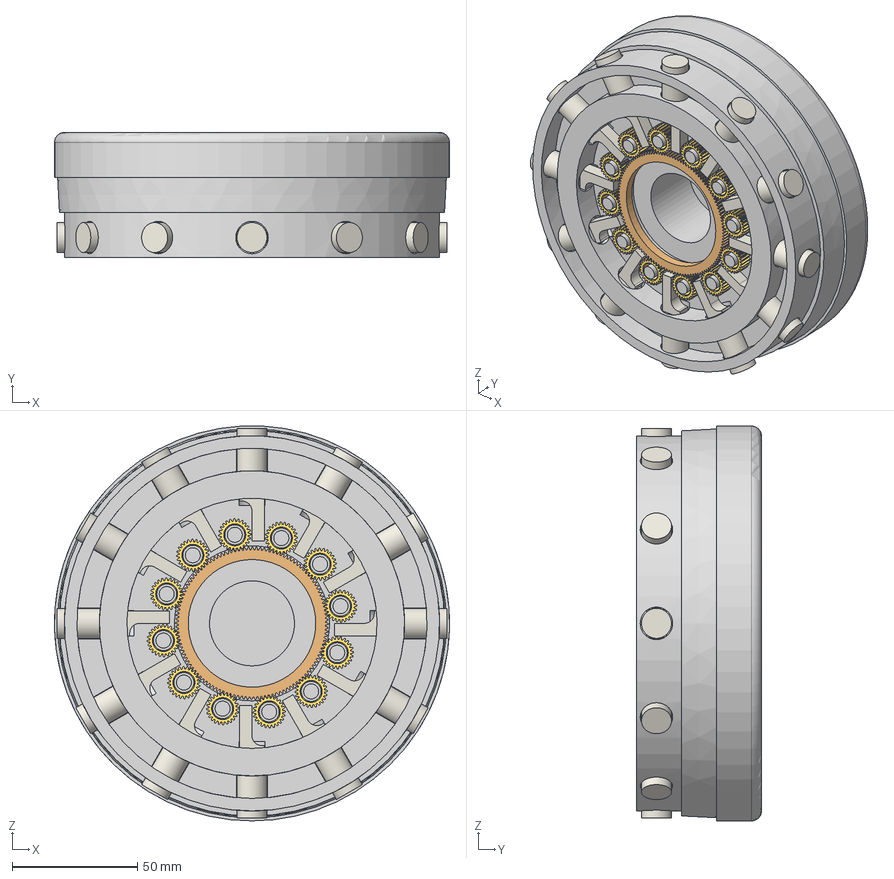
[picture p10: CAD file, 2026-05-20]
step-source/faithful-vault.step
157.9 x 50.0 x 157.9 mm
Spur gear (24 teeth) x 12
Spur gear (120 teeth)

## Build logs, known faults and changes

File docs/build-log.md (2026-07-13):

---
title: Build log
---

# Build log — all posts

Every post on the development blog, newest first.

{% for post in site.posts %}
- {{ post.date | date: "%Y-%m-%d" }} — [{{ post.title }}]({{ post.url | relative_url }})
{% endfor %}

Subscribe via the [RSS feed]({{ 'feed.xml' | relative_url }}).

The terse workshop journal — shorter notes, no pictures — lives in
[`log.md`](https://github.com/jmcpheron/vault-study/blob/main/log.md)
in the repo root.

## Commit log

2026-05-20 feat: bootstrap vault-study repo with Shareable CAD pattern
    Initial commit. Sets up the full pycon2026-style "Shareable CAD"
    pipeline, flattened for a single project: a parametric CAD study of
    Adam Savage's 1/12-scale bank-vault door, with a faithful (machined
    replica) variant and an FDM-printer-friendly variant tracked as
    siblings.
    Bootstrap content:
    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
    [fdm-vault.step, unauthorized-vault-clone.step]
2026-05-20 feat: real step_io.inspect + mesh.render_iso + faithful-vs-fdm comparison
    Implements the first slice of the heavy STEP/render pipeline and uses
    it to ship the first data-driven explainer page.
    Kernel:
    - step_io.inspect: real implementation. ASCII parse (no deps) returns
    schema, document name, named PRODUCTs with instance counts, assembly-
    instance count, entity-type histogram. OCP pass (heavy extras) adds
    bounding box and BRepMesh triangle count. Drops the NotImplementedError
    stub; replaces the format_report() output the CLI prints.
    - mesh.render_iso: real implementation. STEP → OCP tessellation → temp
    STL → trimesh.load → matplotlib 3D Poly3DCollection PNG. Headless,
    no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
2026-05-20 feat: 3D OpenSCAD animations, interactive 2D demo, voice scaffolding
    Two slices in one push, picked up where the iso renders left off.
    Visualization layer:
    - parts.py: XCAF-based per-part extraction yielding TopoDS_Shapes.
    Reveals 6 unique parts in FDM, 4 in faithful — Onshape's identically-
    named "Part 1" collapsed to one in the ASCII parse; XCAF separates
    them, including the hex-prism FDM locking pin (the planned anti-
    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
2026-05-20 fix(ci): drawsvg in base deps + CI installs [heavy,dev]
    Two failures from the previous push:
    1. test_schematic collection failed with `ModuleNotFoundError: No
    module named 'drawsvg'` because schematic.py imports drawsvg at
    module top-level but drawsvg was in [heavy] only and CI installs
    [dev].
    2. test_parts and test_scad call iter_named_shapes which needs OCP
    (in [heavy]).
    Fixes:
    - Move drawsvg into base dependencies. It's pure-Python, ~100 KB,
    and the schematic module is core enough that light installs should
    be able to generate 2D SVGs.
    - ci.yml installs `.[heavy,dev]` instead of `.[dev]`. cadquery-ocp
    is ~180 MB but pip's cache (keyed on pyproject.toml) makes later
    r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
2026-05-20 fix(scad): per-role part orientations + per-role colors
    The first cam-sweep / exploded GIFs had parts placed in the right
    radial pattern but rotated wrong — the base's axle-post ring ended up
    perpendicular to the door, the pin's hex prism lay sideways, and the
    ring/spurs hovered above the rest. Root cause: every imported STL got
    the same rotate([90,0,0]) wrapper, but the parts have different
    local-frame conventions in the Onshape STEP export.
    We don't apply the STEP assembly transforms (those live in NAUO
    entries and would need a deeper XCAF walk). Instead, hand-correct per
    role based on each STL's bbox principal axis:
    ring / spur / hub: rotation axis along local +Y → rotate Y→Z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
2026-05-20 feat(docs): pin-travel explainer page + CAD technical drawings
    A new pedagogical resource on the kinematics: how far do the pins
    extend for a given lever throw, and why? The page derives the
    rack-and-pinion identity from first principles, plugs in the vault's
    gear numbers, lays out a ring-angle ↔ pin-travel table, and gates the
    math with a mini-slider that drives a live diagram.
    Three new CAD-software-style technical drawings:
    - technical-top-view.svg — full mechanism with Ø60 ring pitch, Ø72
    spur BCD, 30° spacing, 24/120 tooth counts, Ø10 pin, module 0.5,
    all callouts routed outside the gear-occupied zone so they don't
    collide with the 12 spurs.
    - rack-pinion-closeup.svg —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
2026-06-18 feat(release): Onshape links + `vaultkit release` bundle pipeline
    Wire the two public Onshape docs into the repo and add the
    Onshape -> STEP -> bundle -> Printables/MakerWorld pipeline, stopping
    where it has to: neither platform has an upload API and both block
    bots, so this produces an *uploadable* bundle and leaves the upload
    (and a Pass-2 browser pre-fill) to a human.
    Provenance / the git<->Onshape version link:
    - params.ONSHAPE: an OnshapeSource dataclass per variant holding the
    doc/workspace/element ids + version_id/version_name/exported_utc
    slots. permalink resolves to the immutable /v/<versionId> URL once a
    named Onshape Version is cut, else the live /w/ workspace URL.
    - params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
2026-07-13 chore: remove vault-notes-from-youtube scratch, write the kickoff entry
    Absorb the last two un-ported Onshape tips (rack relief Boolean
    Subtract, slider-mate travel limits) into cad/faithful/onshape.md,
    repoint the links that referenced the scratch directory, and replace
    the kickoff TODO in log.md with a real entry.
    Claude-Session: https://claude.ai/code/session_01HYQpZdsaC1n22vqS6SwBzV
2026-07-13 feat(play): pin-fit tolerance stack-up math, diagram, and CLI table
    New vaultkit.play module (stdlib only): PinFit clearances, tilt over a
    guided length, lateral play at the pin tip, locked-door play, and a
    stackup() table computed per variant. Faithful bore is modeled as a
    zero-clearance slip fit; the FDM bore reads the planned 10.4 mm from
    params (per cad/fdm/deviations.md). Gear backlash stays an input, not
    a constant — no measured figure exists yet.
    New pin-play technical drawing (drawsvg, light deps) with clearances
    exaggerated 10x and every callout computed from params/play. Exposed
    as 'vaultkit play' and 'explain schematic --kind pin-play'; registered
    in 'explain render'. Committed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
2026-07-13 feat(blog): backfill four posts — the math, the revision, the views, the play
    Four dated posts seeded from existing work: the rack-and-pinion
    pin-travel derivation (2026-05-20, matching the drawings commit),
    the 12mm-to-10mm pin revision story harvested from the part-4 notes
    (2026-06-02), the exploded/cam-sweep animations (2026-06-17,
    matching the pipeline commit), and a new pin-play tolerance
    stack-up (2026-07-13) whose table and diagram are computed by
    vaultkit.play. Plus a refocus entry in log.md.
    The stack-up post is timestamped 00:00 UTC — Jekyll drops
    future-dated posts at build time, and a -0700 morning timestamp was
    still in the future for an early-UTC build.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
2026-07-13 docs: README leads with the Onshape model, tooling demoted to supporting act
    New order: the model and how to try it (Onshape link, STEP,
    interactive demo), the FDM conversion, the build blog, then the
    what's-where map and a condensed 'how the visuals get made' section
    absorbing the old Pattern section. SHAREABLE-CAD.md gets a framing
    line; STYLE.md documents the post conventions (one animation per
    viewport, front-matter excerpts, relative_url in posts).
    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
2026-07-13 chore: rename unauthorized-vault-clone.step to faithful-vault.step
    The wink made sense when the STEP was a private inbox file; now that
    'download the files and try it' is the front door, the symmetric
    faithful-vault.step / fdm-vault.step pair is clearer. STYLE.md keeps
    the original name as history.
    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
    [faithful-vault.step]
